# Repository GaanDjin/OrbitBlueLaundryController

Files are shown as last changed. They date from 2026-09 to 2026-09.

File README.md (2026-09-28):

# Orbit Blue Laundry Controller

## First: This project involves Fire, Moving Parts, and Mains Electricity. This can result in burning the place down, being maimed, or death so don't attempt unless you know what you are doing!

### What this is:
An ESP32 firmware designed to talk to a server laundry card tap system (Currently closed source).
RFID tap → REST deduct balance and start machine.
Three profiles divided into 2 projects at the moment: kiosk for checking, loading, and refunding card balances and then the washer/dryer which deduct card balances and control machines.
OTA updates
And remote config via heartbeat.

I took over a small laundromat in the middle of nowhere Nov. 2024 and at the time only about 50% of the machines worked which meant lots of repairing. After I had them *mostly* up and running it became obvious the coin acceptors were a bit of a nightmare. Watching people struggle to work out how the coins worked and the number of times I had to tell them which slot to put the Loonies into (makes me want to cry), I decided I needed to fix that. After looking at some of the available commercial products, which would have been nice, but way too expensive; I decided to build my own, from the ground up. 

Enter: Orbit Blue a Laundry card management system. This would be the hardware end of the system.

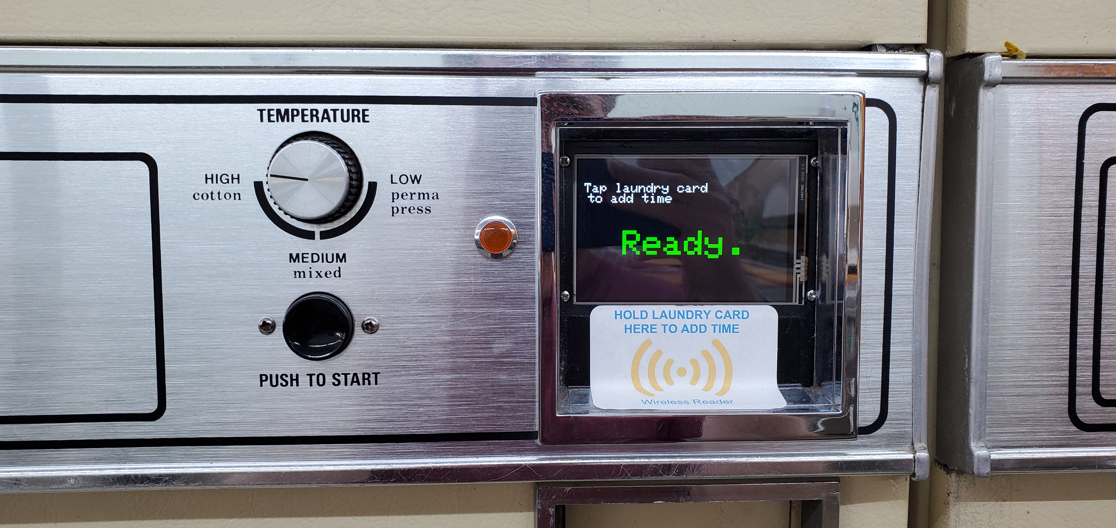
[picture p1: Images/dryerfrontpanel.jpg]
 

Video: [Dryer Start](Images/20260927_091349%20[x264].mp4)

It's hard to see in the video but as I hold the card up to the reader it starts by adding 5 minutes and then adds another 5 minutes. As timer mode is cumulative so every tap (or the longer you hold) will continue to add time up to your card balance.

Video: [Dryer Countdown](Images/20260927_091349%20[x264].mp4)

Video: [Kiosk](Images/balancechecker.mp4)

The balance checker kiosk is what I use to load and refund customer cards and guest cards (Blue fob in the video).

The project is broken into a few parts:

1. The project files for the esp32 micro controllers written in C++ using Visual Studio Code.
2. 3D files for the dryer boxes. Made to fit a Huebsch 30EG Dryer circa 1960s. Made in Blender.
3. PCB board to interface the different parts. Made in EasyEDA.

The old dryer coin drop which would accept quarters and rotate a gear and ratchet to push two switches and activate the dryer:
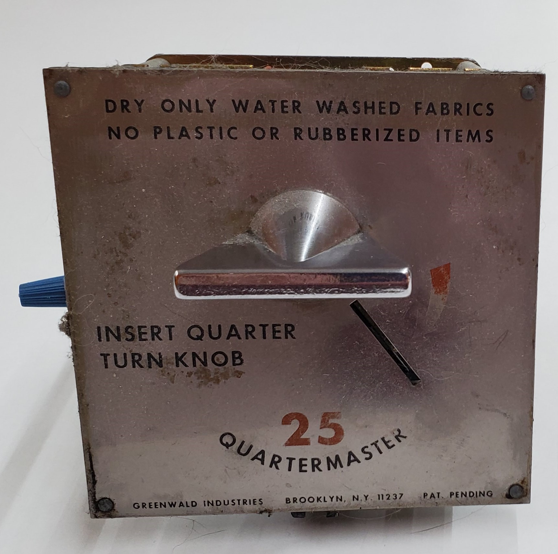
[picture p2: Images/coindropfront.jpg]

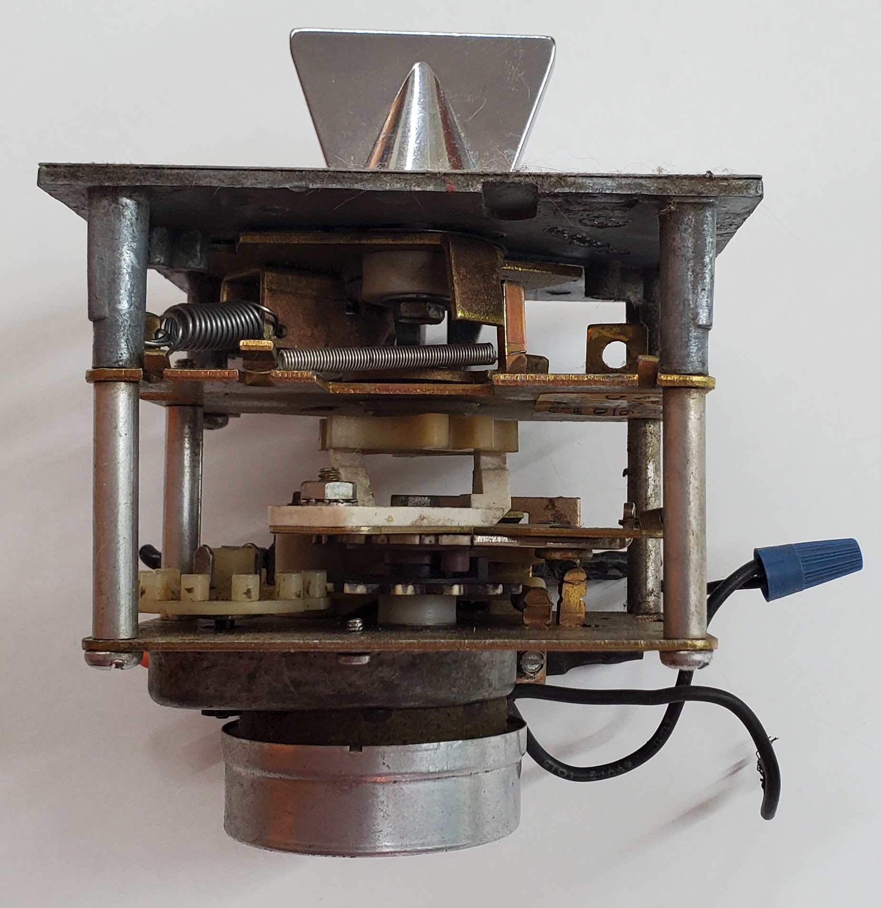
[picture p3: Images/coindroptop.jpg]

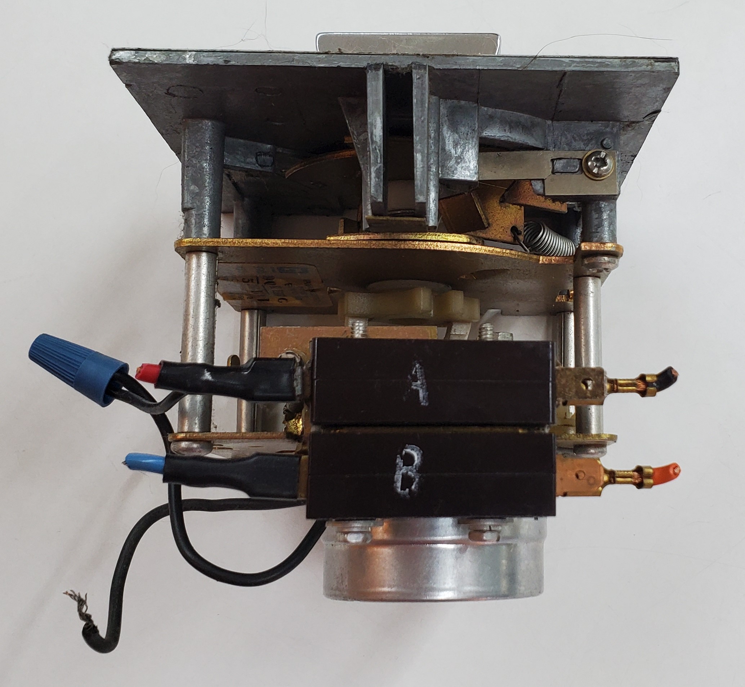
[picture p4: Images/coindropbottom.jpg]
<br />
So they've been $0.25 per 5 min for 60 years. (Or the really cheap, that figured out a Nickel would usually work too)

I tried to make the system as modular as possible so that any one module can fail and be easily replaced without tossing the whole works. I did manage to blow up a relay module putting the front panel back on and it shorted to ground. *Ka-POW* and a puff of smoke. So, again, *LINE VOLTAGE... SCARY*

A Partially assembled dryer box:<br />
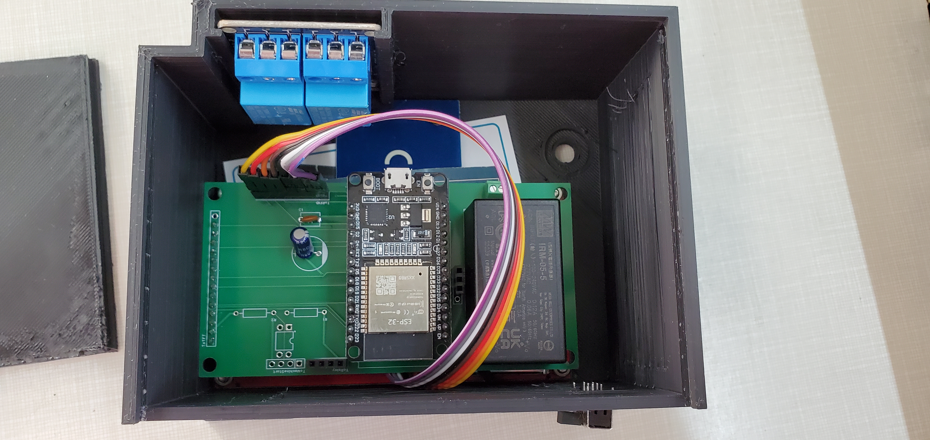
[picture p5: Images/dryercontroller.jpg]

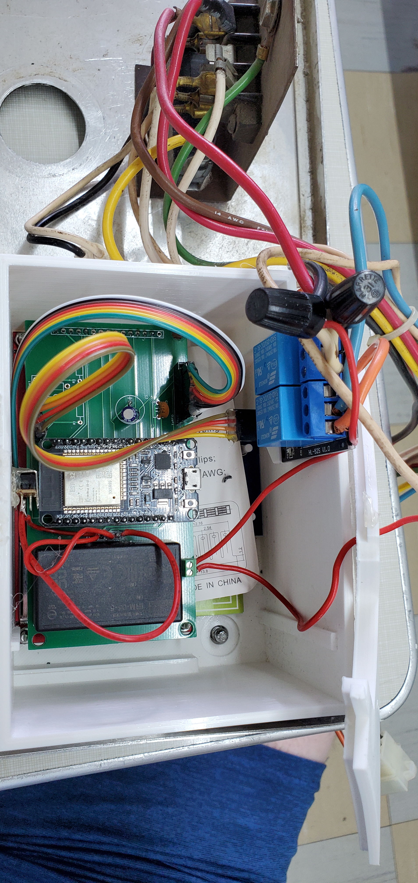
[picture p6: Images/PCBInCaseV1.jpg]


I have yet to make a box for the washer:<br />
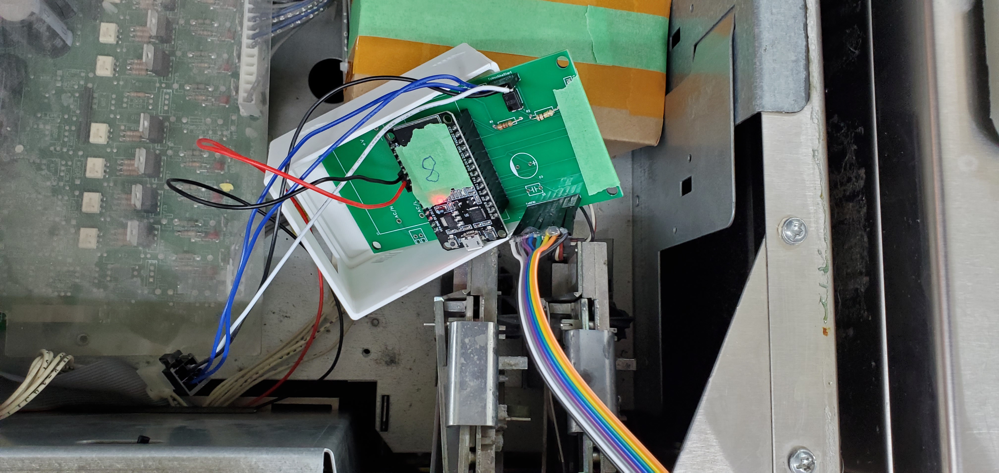
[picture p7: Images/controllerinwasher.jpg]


What the initial test looked like:<br />
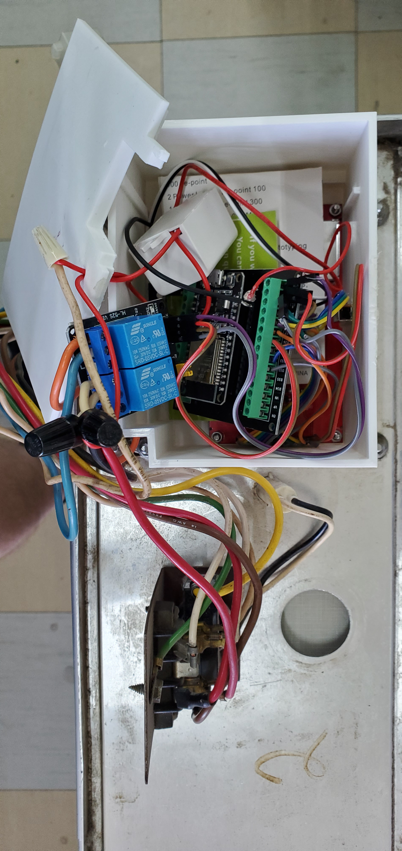
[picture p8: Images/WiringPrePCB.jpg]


The PCB just have to snip the resistor leads:<br />
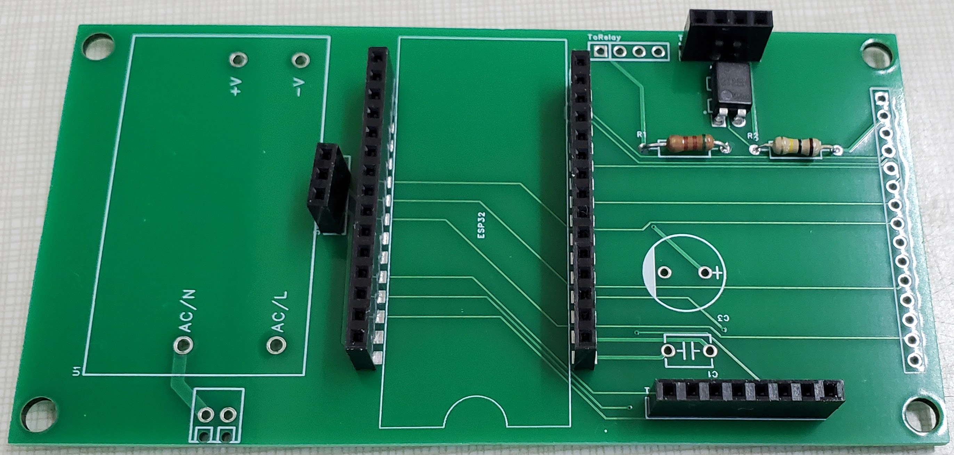
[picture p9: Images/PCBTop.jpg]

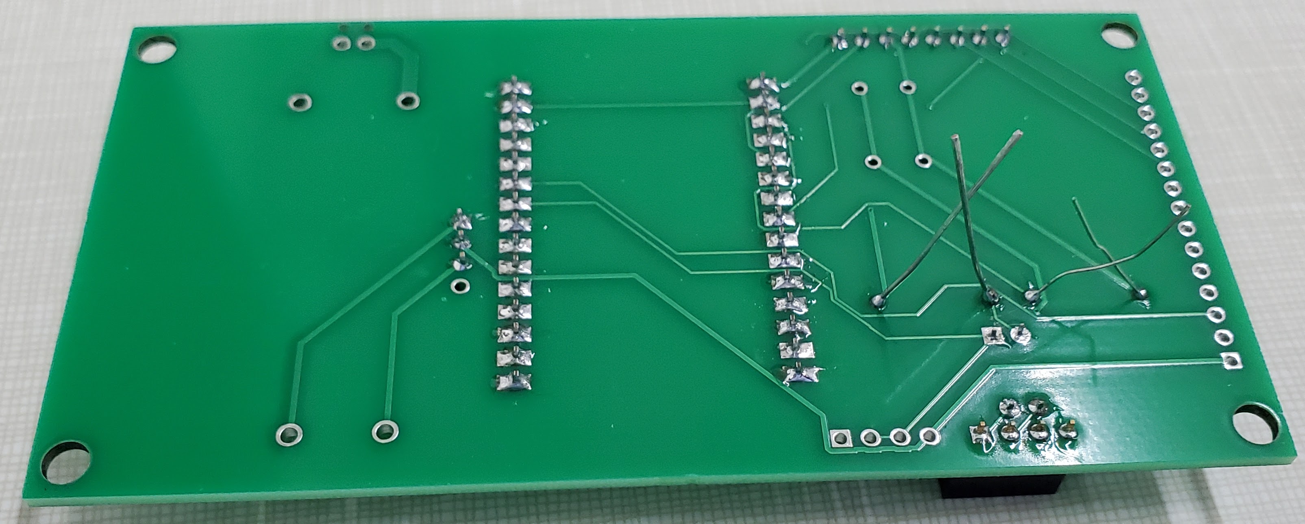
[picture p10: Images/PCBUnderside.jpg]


I designed the PCB to directly piggyback the lcd screen to save space and avoid the extra wiring.<br />
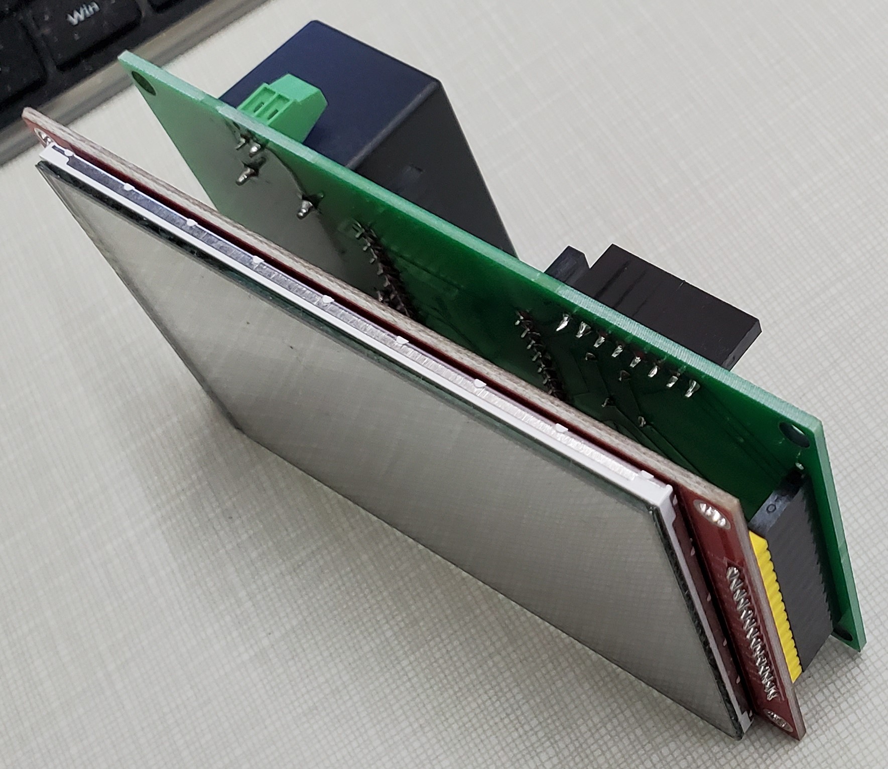
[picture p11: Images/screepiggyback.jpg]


BOM:

ASA Filament for the Dryer boxes. PLA won't cut it as the dryer heat will warp it. <br />
1 x ESP32 Dev board. Specifically: 30PIN ESP32S ESP-WROOM-32 I use [this one](https://www.amazon.ca/dp/B0BQJ8BTVB?th=1)<br />
1 x 5mm LED <-- For Washer as a status indicator<br />
1 x 100k resistor <-- Washer<br />
1 x 480 Ohm resistor <-- Washer<br />
1 x 100 nF Capacitor (#104) <-- Optional to smooth out RFID Power<br />
1 x 10 uF Capacitor <-- Optional to smooth out RFID Power<br />
1 x [6mm High Side Knob 6 Pin 2 Position DPDT Slide Switch](https://www.amazon.ca/20Pcs-50VAC-Position-Switch-SK22H03/dp/B0BKG6Y4KM) <-- Not the ones I went with as I had a bunch laying around but something similar for on/off.<br />
1 x [IRM-05-5 AC to 5v DC](https://www.digikey.ca/en/products/detail/mean-well-usa-inc/IRM-05-5/7704652) <-- A cheap buck converter isn't the greatest because of the EMI the dryers create. Needed if you can't find a 5v supply.<br />
1 x [AQY212EH Solid State Photo-Coupled Relay (Photorelay)](https://www.digikey.ca/en/products/detail/panasonic-industry/AQY212EH/512405) <-- Photo Relay for Washer<br />
1 x [Two Channel Relay Module](https://www.aliexpress.com/item/10000000669335.html?spm=a2g0o.order_list.order_list_main.147.36d618020lMnqG) <-- OR Two Channel Relay for Dryer<br />
1 x [RC522 RFID Module](https://www.digikey.ca/en/products/detail/sunfounder/CN0090/18668629) <-- *Be very wary of cheap knockoffs on Amazon and AliExpress I ended up scrapping 25 of them* Even the official ones I have to reset them every minute because they have a tendency to stop working. <br />
2 x [15-pin connection header](https://www.digikey.ca/en/products/detail/sullins-connector-solutions/PPTC151LFBN-RC/810153) <-- To mount the esp32 to the PCB<br />
1 x [14-pin connection header](https://www.digikey.ca/en/products/detail/sullins-connector-solutions/PPTC141LFBN-RC/810152) <-- To connect the LCD to the PCB<br />
1 x [8-pin connection header](https://www.digikey.ca/en/products/detail/sullins-connector-solutions/PPTC081LFBN-RC/810147) <-- To Connect the RFID to the PCB<br />
3 x [4-pin connection header](https://www.digikey.ca/en/products/detail/sullins-connector-solutions/PPTC041LFBN-RC/810144)<br />
1 x [2-pin block terminal 2.54MM PCB](https://www.digikey.ca/en/products/detail/phoenix-contact/1725656/267462)<br />
1 x [4PIN Male for PC Computer ATX CPU Power Connector](https://www.aliexpress.com/item/32607655535.html?spm=a2g0o.order_list.order_list_main.50.36d618020lMnqG)<br />
1 x [4 inch LCD Display](https://www.aliexpress.com/item/1005005787550807.html?spm=a2g0o.order_list.order_list_main.65.36d618020lMnqG)<br />
Dupont Wire Male to Female:<br />
8-pins for RFID<br />
4-pins for Relay<br />
I couldn't find a source of just male to female so went with [ELEGOO 120pcs 20cm Multicolored Dupont Wire](https://www.amazon.ca/dp/B01EV70C78?th=1) or [RGBZONE 120pcs 20CM Multicolored Dupont](https://www.amazon.ca/dp/B01M1IEUAF?th=1)<br />
Also used them as wires for the switches<br />

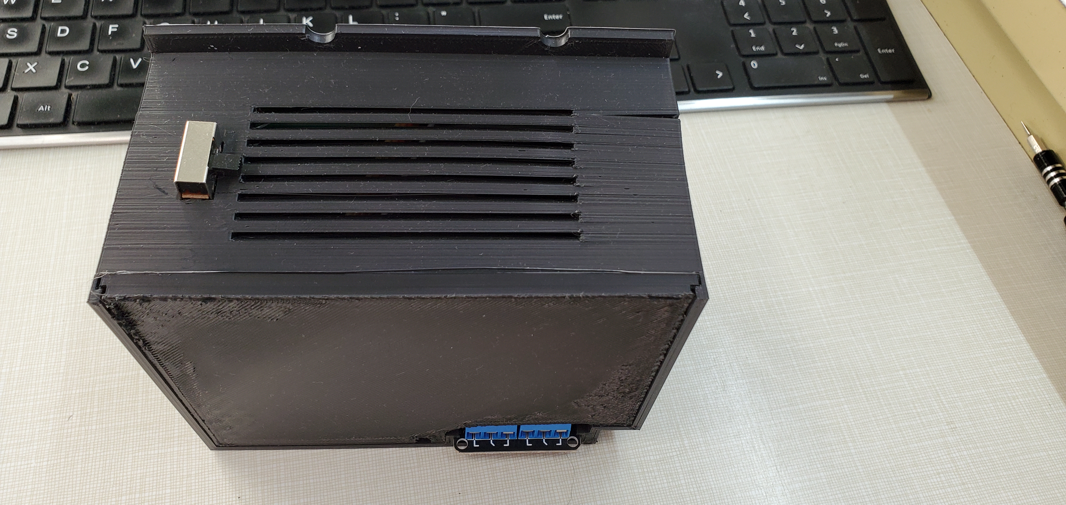
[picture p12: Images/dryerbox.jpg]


# Setup and Provisioning:
I'm going to assume a couple things so I'll glaze over installing the right drivers ([cp2102](https://www.silabs.com/software-and-tools/usb-to-uart-bridge-vcp-drivers?tab=downloads)) to talk to the esp32 and setting up PlatformIO on VS Code.

Upon initial flash the esp32 will go into provisioning mode. 
Here you can enter the wifi SSID and Password along with the login information for the controller to talk to the server. 
Once you press the "Connect & Save" button the esp32 will reboot and attempt to connect. If successful the config will be saved and you are good to go! If the login to wifi or the server fail it will reboot back to provisioning mode.

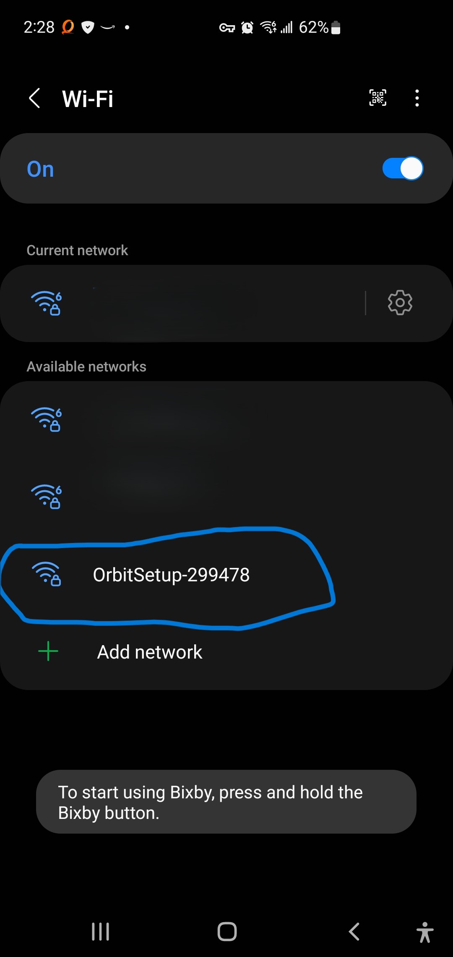
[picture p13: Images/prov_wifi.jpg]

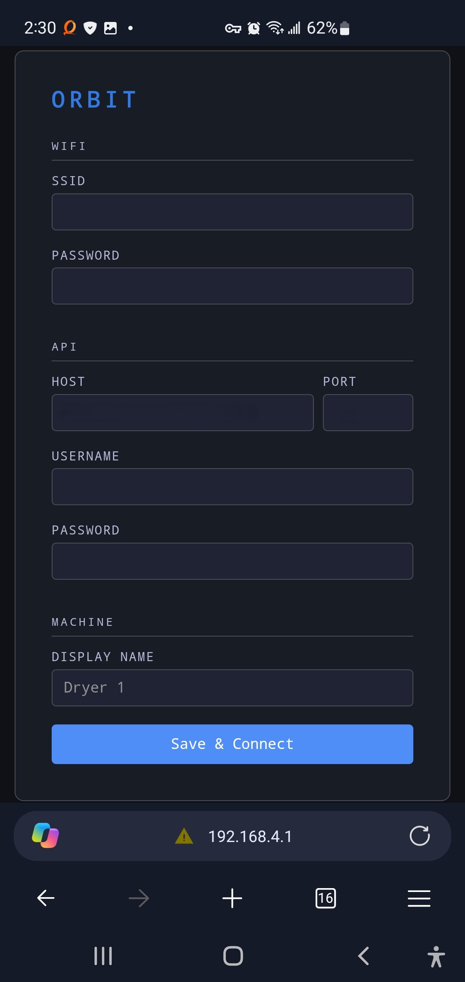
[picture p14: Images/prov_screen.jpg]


A few notes here:
The wifi must be 2.4GHz. 
The password shouldn't have any special characters in it. You might have better luck with that but I had to go Alphanumeric between all the microprocessors I have in the laundromat.
The server port is actually default port 80 unencrypted. Then switches to the specified port with SSL if port 80 failed. I found the wakeup to init into SSL was too long and people would get frustrated waiting for at least 2 seconds for the connection to be made. 

# Config in profiles:
In the platformio.ini file we can use build_flags to control some fundamental parts in the firmware:

```
    -D HAS_DISPLAY <-- When included the display will be used and when excluded the whole display library is skipped. The washer doesn't have a screen in my laundromat so this is off in the washer profile.
    -D HAS_TOUCH <-- Optional but follows the same logic as HAS_DISPLAY. When touch is enabled on the dryers it dims the screen and brightens when in use or touched.
    -D HAS_LED_RED <-- For the washers the rfid box has a red LED that will turn red upon tap and blink if there is insufficient funds. 
    -D RELAY_ON_START <-- While booting should the relay be on (Off by default). I use this on the dryer so that when the controller reboots it keeps the dryer running until it's back up and connected again.
    -D RELAY_ACTIVE=false <-- Used to indicate if the relay is closed when idle or open. Typically one would want open (Off) when idle.
    -D HAS_MACHINE_BUSY <-- Tells the esp32 to listen to the machine to determine if its running or not. While the machine is running extra taps should be ignored.
    -D FIRMWARE_PROFILE='"dev"' <-- The profile is used during OTA updating.
    -D FIRMWARE_VERSION='"1.1.2"' <-- The firmware version. Update this when making changes.
```

Config.h has some settings that can be adjusted:

```
API_HOST <-- Can be ignored. Set during provisoning.
API_PORT <-- Can be ignored. More in the provisioning section.
testInitDnsHost <-- The host to attempt to ping on boot as a network test. Doesn't affect functionality and is only useful when connected to serial or to monitor on the firewall.
CLEAR_PROVISION <-- Tells the esp32 to clear settings on boot. Needed when you want to reset the firmware to default. For instance changing the wifi password or login info on the esp32.
CLEAR_CLIENT_PREFS <-- Clears the login token on boot so the esp32 will always call /login rather than reusing the bearer token in memory.
HEARTBEAT_INTERVAL_MS <-- How often to send a heartbeat to the server. Default: 30000UL
HEARTBEAT_TIMEOUT_MS <-- How long a heartbeat should be missed before rebooting to attempt a reconnection. Default: 600000UL
TAP_COOLDOWN_MS <-- How long a card has to be visible to the reader before a new tap is registered. Used in cumulative mode. Default: 1000UL
WAKEUP_COOLDOWN_MS <-- How long between resetting the RFID reader. Default: 10000UL
ACCUM_COMMIT_OFFSET_MS <-- A buffer to wait when the card disappears before committing to deduct funds. Default: 200UL
BALANCE_DISPLAY_MS <-- How long to show the new balance on screen after funds have been deducted. Default: 10000UL
```
<br />
Globals.h

```
CONFIG_FETCH_INTERVAL_MS <-- Determines how often to get config from the server.
```

<br />
Globals.cpp stores the global variables used in the program. One variable to take not of in here is the "Amount". The default value of Amount should be set to the default price of the machines.<br /> 
I've recently had an issue with my VM Host playing up and temporarily locking up the server VM causing the controllers to reboot very infrequently. When they do reboot if they don't get a config right away this will be the amount they deduct during tap until the next time they get a config.<br />

```
double        Amount              = 5;
```

One thing to be aware of: The GFX Library for Arduino in PlatformIO is missing "esp32-hal-periman.h"<br />
```
.pio\libdeps\dev\GFX Library for Arduino\src\databus\Arduino_ESP32SPI.h
.pio\libdeps\washer\GFX Library for Arduino\src\databus\Arduino_ESP32SPI.h
.pio\libdeps\dryer\GFX Library for Arduino\src\databus\Arduino_ESP32SPI.h
```

Lines 21 & 22 need to be commented out if it complains:

```
//#include "esp32-hal-periman.h"
//#include "esp_private/periph_ctrl.h"
```

# Endpoints used:

Currently the API server I am using Orbit Blue server is closed source, But these are the endpoints the firmware uses and what they expect. Written in C#/.NET.

## POST "/Login"
Logs into the server with the username and password of the machine and then stores the bearer token data to refresh its login. 

Body: 
```
String body = "{\"username\":\"" + username + "\",\"password\":\"" + password + "\"}";
```
Response:
```
{
"accessToken": string,
"refreshToken": string,
"accessExpiresUtc": Iso8601,
"refreshExpiresUtc": Iso8601
}
```
---
## POST "/refresh"
Renew the login bearer token.

Body:
```
String body = "\" + _refreshToken + "\"";
```
Response:
```
{
"accessToken": string,
"refreshToken": string,
"accessExpiresUtc": Iso8601,
"refreshExpiresUtc": Iso8601
}
```

Iso8601 Format: YYYY-MM-DDTHH:MM:SS
Example: 2026-02-28T20:43:46.8152824+00:00

---
## GET "/accounts/current"
Used to validate the bearer token. On error attempt to log in again.
The response content is ignored here. Only that we get a 200 OK response or not. 

---
## GET "/machineconfig/current"
Gets the config from the server. Same as the UpdateConfig command from heatbeat.

Response:
```
{
  "timerMode" : bool,    <-- True: The controller should hold the relay open for cycleLengthSeconds. This is cumulative. False: the controller will pulse out to the machine start pin.
  "cycleLengthSeconds : ulong, <-- How long each tap should run for when in timer mode.
  "amount" : double, <-- How much each tap costs.
  "coinMode" : bool, <-- Coin mode determines if the controller should pulse out once for machine start or pulse repeatedly to simulate a coin drop signal. 
  "coinCount" : int, <-- The number of coin pulses to send in coin mode.
  "coinPulseDuration" : int, <-- How long the machine start and coin pulses should stay "on"
  "coinPulseDelay" : int, <-- How long to wait between coin drop pulses 
  useMachineBusy" : bool, <-- If the machine has a machine busy pin use it to update status with running and ignore taps until the machine is finished.
  "busyCooldownSeconds" : int, <-- If the machine does not have a busy pin then this is how long the controller will issue a status of busy and ignore further taps. Gives a good estimate of when a washer is busy but has no status pin.
  "screenTimeout" : int, <-- How long the screen should stay bright before dimming. 
  "timeRemaining" : int <-- When in timer mode if the esp32 controller has rebooted this can be used to tell the controller how long it has left on the current cycle.
}
```

---
## POST /machines/heartbeat
Send a status update to the server and gets a command from the server if there is one. 

Body:
```
switch (status) {
  case MachineStatus::Running:    statusStr = "Running";    break;
  case MachineStatus::Error:      statusStr = "Error";      break;
  case MachineStatus::OutOfOrder: statusStr = "OutOfOrder"; break;
  default:                        statusStr = "Idle";       break;
}

String body = {"status": status}
```
Response:
```
{
  "command": command string,
  "commandPayload", ""
}

Command String can be one of:

  "" <-- Empty no orders.
  "TryAgain"
  "AddTime" <-- commandPayload will be an int counting the number of seconds to add.
  "Cancel"
  "Reboot"
  "OutOfOrder"
  "InOrder"
  "UpdateFirmware" <-- commandPayload will be either empty or the profile to download "kiosk", "washer", or "dryer". If empty then the firmware uses whatever FIRMWARE_PROFILE was set to during initial flash.
  "UpdateConfig" <-- commandPayload will be a json object containing the controllers config:

{
  "timerMode" : bool,    <-- True: The controller should hold the relay open for cycleLengthSeconds. This is cumulative. False: the controller will pulse out to the machine start pin.
  "cycleLengthSeconds : ulong, <-- How long each tap should run for when in timer mode.
  "amount" : double, <-- How much each tap costs.
  "coinMode" : bool, <-- Coin mode determines if the controller should pulse out once for machine start or pulse repeatedly to simulate a coin drop signal. 
  "coinCount" : int, <-- The number of coin pulses to send in coin mode.
  "coinPulseDuration" : int, <-- How long the machine start and coin pulses should stay "on"
  "coinPulseDelay" : int, <-- How long to wait between coin drop pulses 
  useMachineBusy" : bool, <-- If the machine has a machine busy pin use it to update status with running and ignore taps until the machine is finished.
  "busyCooldownSeconds" : int, <-- If the machine does not have a busy pin then this is how long the controller will issue a status of busy and ignore further taps. Gives a good estimate of when a washer is busy but has no status pin.
  "screenTimeout" : int, <-- How long the screen should stay bright before dimming. 
  "timeRemaining" : int <-- When in timer mode if the esp32 controller has rebooted this can be used to tell the controller how long it has left on the current cycle.
}

```

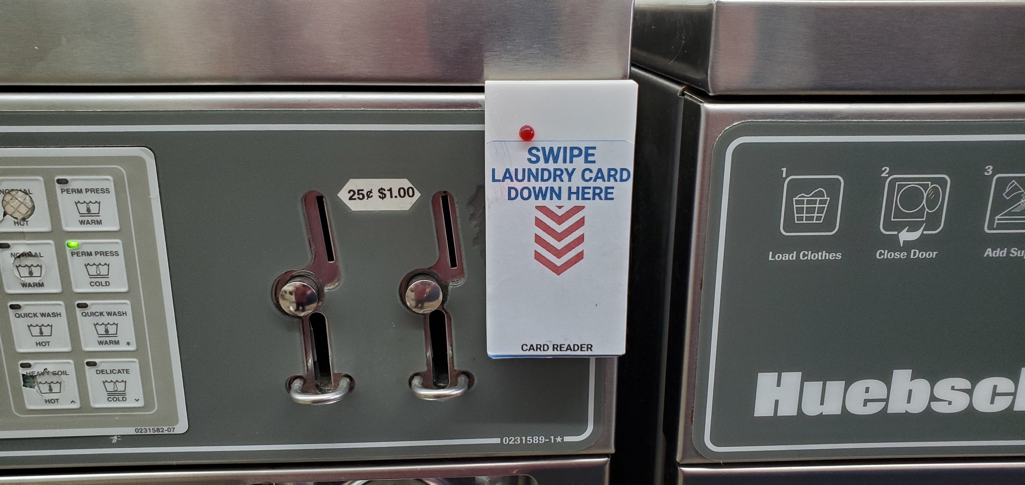
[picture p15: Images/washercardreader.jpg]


---
## POST /tap/deduct
Deduct / remove funds from a customer account given the card id.

Body:
```
String body = {"cardId": "string",  <-- The Hex ID of the RFID card. Must match a card in the database.
    "accountId": "string", <-- Originally used to identify the machine sending the deduct. Now unused always Guid.Zero
    "amount": number, <-- The amount to deduct from that customer account.
    "processorName": "CASH" <-- Processor is kind of a hint to say how this transaction was performed. Currently the firmware is set to "Cash"
    };
```
Response:
```
{
"message": string, <-- A string message if there was a problem.
"newBalance": 0.00, <-- The new account balance
"accountDisplayName": string <-- the Display name of the customer account. Currently unused by the Firmware. 
}
```

---
## POST /tap/refund
Removes funds to the customer account given the card id. Can be marked as refunded on the server to differentiate from a machine using their funds.

Body:
```
{
    "cardId": string,  <-- The Hex ID of the RFID card. Must match a card in the database.
    "amount": number, <-- The amount to refund from that customer account.
    "processorName":"CASH" <-- Processor is kind of a hint to say how this transaction was performed. Currently the firmware is set to "Cash"
}
```
Response:
```
{
"message": string, <-- A string message if there was a problem.
"newBalance": 0.00, <-- The new account balance
"accountDisplayName": string <-- the Display name of the customer account. Currently unused by the Firmware. 
}
```

---
## POST /tap/add
Add funds to the customer account given the card id.

Body:
```
{
    "cardId": string,  <-- The Hex ID of the RFID card. Must match a card in the database.
    "amount": number, <-- The amount to add to that customer account.
    "processorName": "CASH" <-- Processor is kind of a hint to say how this transaction was performed. Currently the firmware is set to "Cash"
}
```
Response:
```
{
"message": string, <-- A string message if there was a problem.
"newBalance": 0.00, <-- The new account balance
"accountDisplayName": string <-- the Display name of the customer account. Currently unused by the Firmware. 
}
```

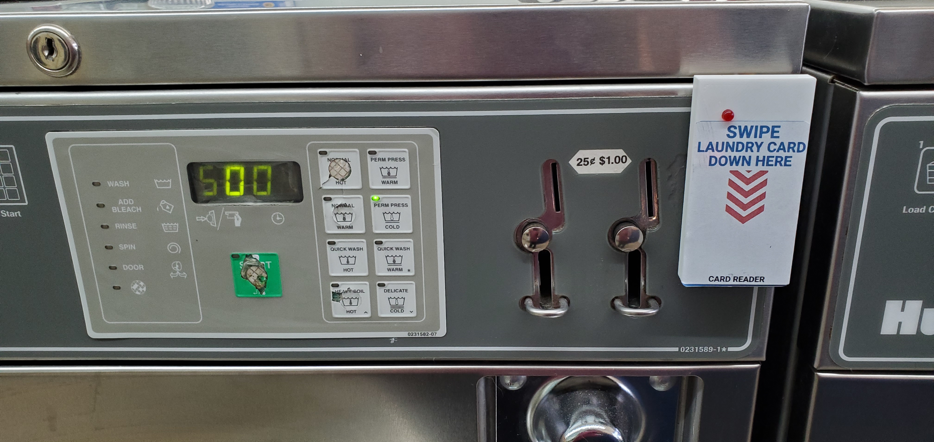
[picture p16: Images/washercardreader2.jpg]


---
## GET "/cards/list?Filters[CardId]=%cardId%"
Used to check if the card being tapped is an admin card. The response can have lots of other details but this is the only field we care about.

Response:
```
{
  rows: [
    {
      isAdminCard: bool
    } 
  ]
}
```

---
## GET "/time"
Currently unused.

---
## GET "/tap/%cardId%/balance"
```
Where %cardId% is the Hex ID of the RFID card
```
Response:
```
{
  "balance": 0.00 <-- The current balance of the customer account for that card.
}
```

---
## GET "/firmware/version?profile=" + profile
Checks to see if the server has a new firmware for an over the air update. 

Response:
```
{
  version: string <-- The version number for example "1.0.17" of the latest version on the server. If the value is different (not necessarily higher) then download the version from the server.
}
```

---
## GET "/firmware/download?profile=" + profile
Download the new firmware from the server and perform an update. As HTTPUpdate on ESP32 Arduino core doesn't support authentication this must be \[AllowAnonymous\].

Response:
```
File: application/octet-stream
```

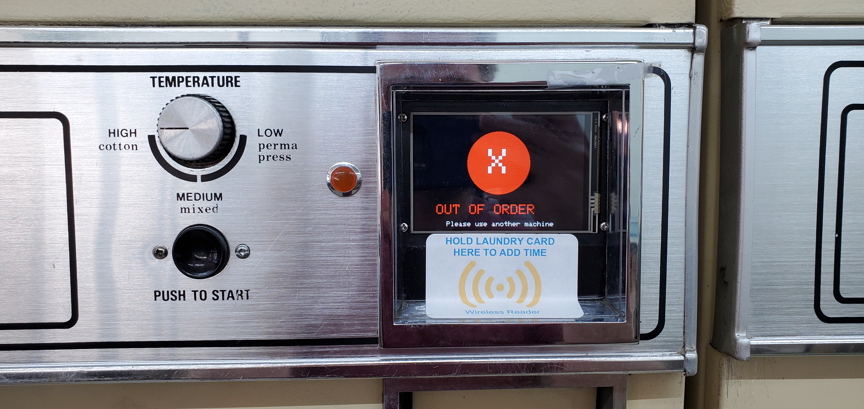
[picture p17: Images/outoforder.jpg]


There was a bit of trial and error getting the right components, learning about counterfeit electronics, and iterating through what works and what works better.
But, it has been a great project and tons of fun to go through the whole process learning how the machines work and how to interface with them. 

Hopefully, you might find this as a useful starting point for your own hardware projects. Happy building!

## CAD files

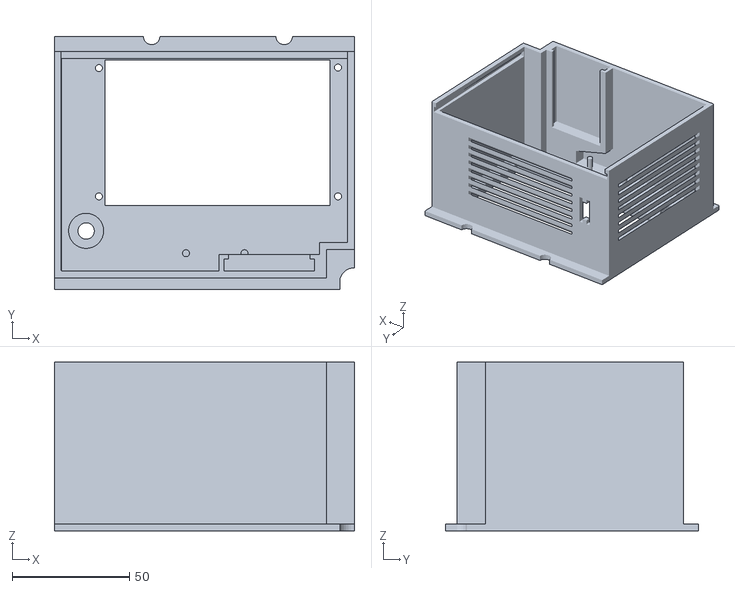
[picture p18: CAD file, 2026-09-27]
Dryer Controls - The Box v2.stl
128.0 x 108.0 x 72.0

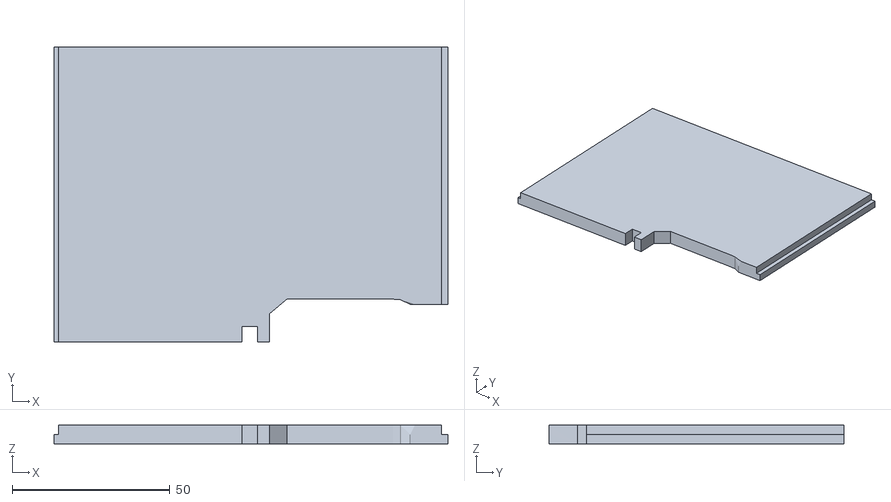
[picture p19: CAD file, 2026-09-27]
Dryer Controls - The Lid v2.stl
125.0 x 93.7 x 6.00

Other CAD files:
Dryer Timer esp32 with LCD and RFID Box.blend

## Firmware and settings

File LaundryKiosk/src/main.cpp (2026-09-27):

#include <main.h>
#include "esp_system.h"

// ── RFID objects ──────────────────────────────────────────────────────────────

#if defined(HAS_TOUCH)
  // touchSPI is owned by Touch.cpp — RFID piggybacks on the same bus
  extern SPIClass* touchSPI;
#else
  // No touch — we own the HSPI bus here
  SPIClass* touchSPI = new SPIClass(HSPI);
#endif

MFRC522DriverPinSimple* ss_pin  = nullptr;
MFRC522DriverSPI*       driver  = nullptr;
MFRC522*                mfrc522 = nullptr;


// ── Provisioned credentials ───────────────────────────────────────────────────
ProvisionData provData;

// ── Accumulation state (unused in kiosk mode, but declared in main.h) ─────────
String        accumulatingCardId  = "";
float         accumulatedAmount   = 0.0f;
int           accumulatedSeconds  = 0;
float         accumulatedBalance  = 0.0f;
unsigned long lastAccumRead       = 0;
bool          isAccumulating      = false;

// ── State ─────────────────────────────────────────────────────────────────────
static unsigned long lastHeartbeatMs = 0;

// ─────────────────────────────────────────────────────────────────────────────
// RFID helpers
// ─────────────────────────────────────────────────────────────────────────────

void setupRFID() {
#if !defined(HAS_TOUCH)
    touchSPI->begin(SPI2_SCK, SPI2_MISO, SPI2_MOSI);
#endif
    // Now construct in the correct order, after SPI bus is up
    ss_pin  = new MFRC522DriverPinSimple(RFID_SS);
    driver  = new MFRC522DriverSPI{*ss_pin, *touchSPI};
    mfrc522 = new MFRC522{*driver};

    Serial.println("[RFID] Initialising...");
    if (!mfrc522->PCD_Init()) {
        Serial.println("[RFID] Init failed!");
    } else {
        MFRC522Debug::PCD_DumpVersionToSerial(*mfrc522, Serial);
        Serial.println("[RFID] Ready.");
    }
}

String printUid(const MFRC522::Uid uid) {
        String hex = "";
    for (size_t i = 0; i < uid.size; i++) {
        if (uid.uidByte[i] < 0x10) hex += "0";
        hex += String(uid.uidByte[i], HEX);
    }
    hex.toUpperCase();
    return hex;
}

bool rfidHealthy() {
    bool ok = mfrc522 && mfrc522->PCD_PerformSelfTest();
    digitalWrite(RFID_SS, HIGH);
    touchSPI->endTransaction();
    return ok;
}

void resetRFIDModule() {
    if (mfrc522) mfrc522->PCD_Reset();
    delay(50);
    if (mfrc522) mfrc522->PCD_Init();
}

// Polls for a new card and reads its serial.
// Explicitly cleans up the SPI bus after every call so the shared HSPI bus
// is fully released before the XPT2046 touch controller gets its turn.
// Returns true if a card UID is ready in mfrc522->uid.
static bool rfidPoll() {
    bool cardPresent = mfrc522->PICC_IsNewCardPresent();
    // RFID_SS may still be asserted — force deassert and close any open transaction
    digitalWrite(RFID_SS, HIGH);
    touchSPI->endTransaction();

    if (!cardPresent) return false;

    bool gotSerial = mfrc522->PICC_ReadCardSerial();
    digitalWrite(RFID_SS, HIGH);
    touchSPI->endTransaction();

    return gotSerial;
}

// ─────────────────────────────────────────────────────────────────────────────
// Machine stubs (kiosk — no relay, no cycle)
// ─────────────────────────────────────────────────────────────────────────────

void  startMachineCycle()             { /* kiosk: not used */ }
void  addCycleTime(int /*seconds*/)   { /* kiosk: not used */ }
void  cancelCycle()                   { /* kiosk: not used */ }
bool  machineIsRunning()              { return false; }
void  commitAccumulation()            { /* kiosk: not used */ }
void  applyConfig(const String& /*j*/){ /* kiosk: not used */ }
void  fetchConfig()                   { /* kiosk: not used */ }

// ─────────────────────────────────────────────────────────────────────────────
// WiFi
// ─────────────────────────────────────────────────────────────────────────────

void connectWifi() {
    showConnecting();
    WiFi.mode(WIFI_STA);
    WiFi.begin(provData.wifiSsid.c_str(), provData.wifiPass.c_str());
    unsigned long start = millis();
    while (WiFi.status() != WL_CONNECTED) {
        if (millis() - start > 15000) {
            Serial.println("[WiFi] Timeout — rebooting.");
            ESP.restart();
        }
        delay(250);
    }
    showConnected();
    Serial.println("[WiFi] Connected: " + WiFi.localIP().toString());
}

// ─────────────────────────────────────────────────────────────────────────────
// Auth
// ─────────────────────────────────────────────────────────────────────────────


bool ensureAuthenticated() {
    // Wait for NTP to sync so time() is valid for expiry checks
    time_t now = time(nullptr);
    while (now < 1000000000UL) {
        delay(100);
        now = time(nullptr);
    }

    // Try to load cached credentials
    if (api->loadCredentials()) {
        if (api->needsRelogin()) {
            Serial.println("[Auth] Refresh token expired — full login.");
        } else if (api->needsRefresh()) {
            Serial.println("[Auth] Access token expiring — refreshing.");
            if (api->refreshToken()) return true;
            Serial.println("[Auth] Refresh failed — full login.");
        } else {
            // Verify the cached token actually works before trusting it
            // This catches wrong port/host after re-provisioning
            Serial.println("[Auth] Verifying cached token...");
            String response;
            if (api->get("/accounts/current", response, true)) {
                Serial.println("[Auth] Cached token valid.");
                return true;
            }
            Serial.println("[Auth] Cached token rejected — full login.");
            api->clearCredentials();
        }
    }

    // Full login
    Serial.println("[Auth] Logging in...");
    if (api->login(provData.apiUser, provData.apiPass)) {
        Serial.println("[Auth] Logged in!");
        if (!provData.verified) {
            markProvisionVerified();
            provData.verified = true;
        }
        return true;
    }

    Serial.println("[Auth] Login failed!");
    if (!provData.verified) {
        // Never successfully logged in — bad credentials, reprovision
        Serial.println("[Auth] Never verified — clearing provisioning.");
        clearProvisionData();
    } else {
        // Worked before — infrastructure problem, reboot and retry
        Serial.println("[Auth] Previously verified — rebooting to retry.");
    }
    #if defined(HAS_DISPLAY)
        showRebooting();
    #endif
    delay(1000);
    ESP.restart();
    return false;  // unreachable
}

// ─────────────────────────────────────────────────────────────────────────────
// Heartbeat  (always reports Idle for the kiosk)
// ─────────────────────────────────────────────────────────────────────────────

void doHeartbeat() {
    if (millis() - lastHeartbeat < HEARTBEAT_INTERVAL_MS) return;
    lastHeartbeat = millis();

    MachineStatus currentStatus = isOutOfOrder        ? MachineStatus::OutOfOrder
                                 : machineIsRunning() ? MachineStatus::Running
                                                      : MachineStatus::Idle;
    HeartbeatResponse hb = api->sendHeartbeat(currentStatus);

    if (!hb.ok) {
        Serial.println("[Heartbeat] Failed — will retry next cycle");


        // Heartbeat hasn't succeeded in too long (server unreachable)
        if (lastHeartbeat - lastSuccessfulHeartbeat > HEARTBEAT_TIMEOUT_MS) {
            Serial.println("[Heartbeat] Timeout — rebooting.");
            ESP.restart();
        }

        return;
    }

    lastSuccessfulHeartbeat =  millis();

    switch (hb.command) {
        case MachineCommand::None:                                         break;
        case MachineCommand::TryAgain:    startMachineCycle();            break;
        case MachineCommand::AddTime:     addCycleTime(hb.commandPayload.toInt()); break;
        case MachineCommand::Cancel:      cancelCycle();                  break;
        case MachineCommand::UpdateConfig: applyConfig(hb.commandPayload); break;
        case MachineCommand::UpdateFirmware:
            Serial.println("[OTA] Update command received.");
            #if defined(HAS_DISPLAY)
                // TODO: showUpdating();
            #endif
            api->checkAndApplyFirmwareUpdate(
                hb.commandPayload.isEmpty() ? String(FIRMWARE_PROFILE) : hb.commandPayload,
                String(FIRMWARE_VERSION));
            break;
        case MachineCommand::Reboot:
#if defined(HAS_DISPLAY)
            showRebooting();
#endif
            delay(1000);
            ESP.restart();
            break;
        case MachineCommand::OutOfOrder:
            Serial.println("[Machine] Out of order.");
            isOutOfOrder = true;
            #if defined(HAS_DISPLAY)
                showOutOfOrder();
            #endif
            break;
        case MachineCommand::InOrder:
            Serial.println("[Machine] Back in order.");
            isOutOfOrder = false;
            #if defined(HAS_DISPLAY)
                showReady();
            #endif
            break;
    }
}


// ─────────────────────────────────────────────────────────────────────────────
// Kiosk state machine
// ─────────────────────────────────────────────────────────────────────────────

enum class KioskState : uint8_t {
    IDLE,
    BALANCE_SHOWN,       // balance on screen, Admin button visible
    ADMIN_MENU,          // Add / Deduct / Back
    ADMIN_AMOUNT,        // numpad — enter dollar amount
    ADMIN_AWAITING_CARD, // waiting for admin tap to authorise
    ADMIN_RESULT,        // brief success/fail screen
};

static KioskState       kioskState       = KioskState::IDLE;
static unsigned long    stateEnteredMs   = 0;
static String           pendingCardId    = "";    // customer card receiving funds
static float            pendingAmount    = 0.0f;  // amount entered on numpad
static String           amountStr       = "";    // raw digit string while typing
static bool             pendingIsDeduct  = false; // true = deduct, false = add

static void enterState(KioskState s) {
    kioskState     = s;
    stateEnteredMs = millis();
}

// ─────────────────────────────────────────────────────────────────────────────
// Touch helpers
// XPT2046 with setRotation(3): raw X maps to screen X (0-480),
// raw Y maps to screen Y (0-320).  Calibration is approximate — adjust the
// min/max constants if your panel reads differently.
// ─────────────────────────────────────────────────────────────────────────────

#if defined(HAS_TOUCH)
static const int TS_MINX = 200,  TS_MAXX = 3800;
static const int TS_MINY = 200,  TS_MAXY = 3800;
static const int SCR_W   = 480,  SCR_H   = 320;

struct TPoint { int x; int y; bool valid; };

static TPoint getTouchPoint() {
    if (!touch->tirqTouched() || !touch->touched())
        return {0, 0, false};
    TS_Point p = touch->getPoint();
    int sx = map(p.x, TS_MINX, TS_MAXX, 0, SCR_W);
    int sy = map(p.y, TS_MINY, TS_MAXY, 0, SCR_H);
    sx = constrain(sx, 0, SCR_W - 1);
    sy = constrain(sy, 0, SCR_H - 1);
    
    Serial.printf("\n[Touch] Touchpoint: %d, %d\n", sx, sy);

    return {sx, sy, true};
}

static bool hitTest(int tx, int ty, int bx, int by, int bw, int bh) {
    return tx >= bx && tx < bx + bw && ty >= by && ty < by + bh;
}
#endif

// ─────────────────────────────────────────────────────────────────────────────
// Screen drawing helpers
// ─────────────────────────────────────────────────────────────────────────────

#if defined(HAS_DISPLAY)

// Draws a filled rounded button with centred label
static void drawButton(int x, int y, int w, int h,
                       uint16_t bg, uint16_t fg,
                       const char* label, uint8_t textSize = 2) {
                    
    Serial.printf("[Display] Draw Button: %d, %d, %d, %d\n", x, y, w, h);
    
    gfx->fillRoundRect(x, y, w, h, 6, bg);
    gfx->drawRoundRect(x, y, w, h, 6, fg);
    gfx->setTextSize(textSize);
    gfx->setTextColor(fg, bg);
    int16_t x1, y1; uint16_t tw, th;
    gfx->getTextBounds(label, 0, 0, &x1, &y1, &tw, &th);
    gfx->setCursor(x + (w - tw) / 2 - x1, y + (h - th) / 2 - y1);
    gfx->print(label);
}

// ── Admin button geometry (top-right corner) ──────────────────────────────────
#define ADMIN_BTN_X  370
#define ADMIN_BTN_Y    6
#define ADMIN_BTN_W   104
#define ADMIN_BTN_H    36

static void drawAdminButton() {
    drawButton(ADMIN_BTN_X, ADMIN_BTN_Y, ADMIN_BTN_W, ADMIN_BTN_H,
               0x2104 /*dark grey*/, WHITE, "Admin", 2);
}

#endif // HAS_DISPLAY

// ─────────────────────────────────────────────────────────────────────────────
// Idle screen
// ─────────────────────────────────────────────────────────────────────────────

static void showKioskIdle() {
    pendingCardId = "";
    pendingAmount = 0.0f;
    amountStr     = "";
    enterState(KioskState::IDLE);
#if defined(HAS_DISPLAY)
    gfx->fillScreen(BLACK);
    gfx->setTextColor(GREEN, BLACK);
    gfx->setTextSize(4);
    gfx->setCursor(80, 130);
    gfx->print("Check your");
    gfx->setCursor(60, 185);
    gfx->print("Balance here");
#endif
}

// ─────────────────────────────────────────────────────────────────────────────
// Balance screen  (with Admin button)
// ─────────────────────────────────────────────────────────────────────────────

static void showBalance(float balance, const String& cardId) {
    pendingCardId = cardId;
    enterState(KioskState::BALANCE_SHOWN);
#if defined(HAS_DISPLAY)
    gfx->fillScreen(BLACK);

    // "Balance" label
    gfx->setTextSize(4);
    gfx->setTextColor(WHITE, BLACK);
    gfx->setCursor(140, 100);
    gfx->print("Balance");

    // Dollar amount — large, centred
    char buf[16];
    snprintf(buf, sizeof(buf), "$%.2f", balance);
    gfx->setTextSize(8);
    gfx->setTextColor(GREEN, BLACK);
    int16_t x1, y1; uint16_t w, h;
    gfx->getTextBounds(buf, 0, 0, &x1, &y1, &w, &h);
    gfx->setCursor((SCR_W - w) / 2 - x1, 175);
    gfx->print(buf);

    drawAdminButton();
#endif
}

// ── Admin menu ───────────────────────────────────────────────────────────────
#define MENU_BTN_W  130
#define MENU_BTN_H   70
#define MENU_BTN_Y  110
#define MENU_ADD_X   30
#define MENU_DED_X  175
#define MENU_BCK_X  320
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
void loop() {
    unsigned long now = millis();

    // ── Heartbeat ────────────────────────────────────────────────────────────
    doHeartbeat();

    // ── WiFi watchdog ─────────────────────────────────────────────────────────
    if (WiFi.status() != WL_CONNECTED) {
        if (now - lastWifiCheck > 30000UL) {
            lastWifiCheck = now;
            Serial.println("[WiFi] Still disconnected...");
            if (now - lastWifiConnected > 120000UL) {
                Serial.println("[WiFi] Rebooting.");
                ESP.restart();
            }
        }
    } else {
        lastWifiConnected = now;
    }

    // ── Token refresh ─────────────────────────────────────────────────────────
    if      (api->needsRelogin())  api->login(provData.apiUser, provData.apiPass);
    else if (api->needsRefresh() && !api->refreshToken())  api->login(provData.apiUser, provData.apiPass);

    // ── BALANCE_SHOWN / ADMIN_RESULT timeout → back to IDLE ─────────────────
    if (kioskState == KioskState::BALANCE_SHOWN &&
        now - stateEnteredMs > BALANCE_DISPLAY_MS)
    {
        showKioskIdle();
        return;
    }
    if (kioskState == KioskState::ADMIN_RESULT &&
        now - stateEnteredMs > RESULT_DISPLAY_MS)
    {
        showKioskIdle();
        return;
    }

    // ── Touch handling ────────────────────────────────────────────────────────
#if defined(HAS_TOUCH)
    static bool lastTouched = false;
    TPoint tp = getTouchPoint();

    // Edge-detect: only fire once on press-down, ignore held touch
    if (tp.valid && !lastTouched) {
        lastTouched    = true;
        lastScreenTime = now;

        switch (kioskState) {

        case KioskState::BALANCE_SHOWN:
            // Admin button — top right
            if (hitTest(tp.x, tp.y, ADMIN_BTN_X, ADMIN_BTN_Y, ADMIN_BTN_W, ADMIN_BTN_H)) {
                Serial.println("[Admin] Admin button pressed.");
                enterState(KioskState::ADMIN_MENU);
#if defined(HAS_DISPLAY)
                drawAdminMenu();
#endif
            }
            break;

        case KioskState::ADMIN_MENU:
            if (hitTest(tp.x, tp.y, MENU_ADD_X, MENU_BTN_Y, MENU_BTN_W, MENU_BTN_H)) {
                Serial.println("[Admin] Add selected.");
                pendingIsDeduct = false;
                amountStr = "";
                enterState(KioskState::ADMIN_AMOUNT);
#if defined(HAS_DISPLAY)
                drawNumpad();
#endif
            } else if (hitTest(tp.x, tp.y, MENU_DED_X, MENU_BTN_Y, MENU_BTN_W, MENU_BTN_H)) {
                Serial.println("[Admin] Refund selected.");
                pendingIsDeduct = true;
                amountStr = "";
                enterState(KioskState::ADMIN_AMOUNT);
#if defined(HAS_DISPLAY)
                drawNumpad();
#endif
            } else if (hitTest(tp.x, tp.y, MENU_BCK_X, MENU_BTN_Y, MENU_BTN_W, MENU_BTN_H)) {
                Serial.println("[Admin] Back pressed.");
                // Re-show balance screen — re-fetch so it's fresh
                float bal;
                if (api->getBalance(pendingCardId, bal))
                    showBalance(bal, pendingCardId);
                else
                    showKioskIdle();
            }
            break;

        case KioskState::ADMIN_AMOUNT: {
            // Cancel
            if (hitTest(tp.x, tp.y, CANCEL_BTN_X, CANCEL_BTN_Y, CANCEL_BTN_W, CANCEL_BTN_H)) {
                Serial.println("[Admin] Cancelled.");
                showKioskIdle();
                break;
            }
            // Enter button
            if (hitTest(tp.x, tp.y, ENTER_BTN_X, ENTER_BTN_Y, ENTER_BTN_W, ENTER_BTN_H)) {
                if (handleNumpadKey('E')) {
                    enterState(KioskState::ADMIN_AWAITING_CARD);
#if defined(HAS_DISPLAY)
                    drawAwaitingAdminCard();
#endif
                }
                break;
            }
            // Digit rows
            char pressedKey = 0;
            for (int r = 0; r < 3 && !pressedKey; r++) {
                for (int c = 0; c < 3 && !pressedKey; c++) {
                    int bx = NP_ORIG_X + c*(NP_BTN_W+NP_GAP);
                    int by = NP_ORIG_Y + r*(NP_BTN_H+NP_GAP);
                    if (hitTest(tp.x, tp.y, bx, by, NP_BTN_W, NP_BTN_H))
                        pressedKey = NP_KEYS[r][c];
                }
            }
            // Bottom row
            if (!pressedKey) {
                int by = NP_ORIG_Y + 3*(NP_BTN_H+NP_GAP);
                for (int c = 0; c < 3 && !pressedKey; c++) {
                    int bx = NP_ORIG_X + c*(NP_BTN_W+NP_GAP);
                    if (hitTest(tp.x, tp.y, bx, by, NP_BTN_W, NP_BTN_H))
                        pressedKey = NP_BOT[c];
                }
            }
            if (pressedKey) {
                handleNumpadKey(pressedKey);
#if defined(HAS_DISPLAY)
                refreshAmountDisplay();
#endif
            }
            break;
        }

        case KioskState::ADMIN_AWAITING_CARD:
            // Cancel only — card tap is handled below in the RFID block
            if (hitTest(tp.x, tp.y, CANCEL_BTN_X, CANCEL_BTN_Y, CANCEL_BTN_W, CANCEL_BTN_H)) {
                Serial.println("[Admin] Awaiting-card cancelled.");
                showKioskIdle();
            }
            break;

        default:
            break;
        }
    }
    if (!tp.valid) lastTouched = false;
#endif // HAS_TOUCH

    // ── RFID scan ──────────────────────────────────────────────────────────────
    if (now - lastTapTime > TAP_COOLDOWN_MS && rfidPoll())
    {
        lastTapTime    = now;
        lastScreenTime = now;
        String cardID  = printUid(mfrc522->uid);
        mfrc522->PICC_HaltA();
        mfrc522->PCD_StopCrypto1();
        Serial.println("[RFID] Tap: " + cardID);

        if (kioskState == KioskState::ADMIN_AWAITING_CARD) {
            // ── Admin card verification + fund transfer ──────────────────
            Serial.println("[Admin] Checking card: " + cardID);
            if (!api->isAdmin(cardID)) {
                Serial.println("[Admin] Not an admin card.");
#if defined(HAS_DISPLAY)
                drawAdminResult(false, 0.0f, "Not admin card");
#endif
            } else {
                float newBalance = 0.0f;
                bool ok;
                if (pendingIsDeduct) {
                    String result, displayName;
                    String accountId;
                    ok = api->refund(pendingCardId, accountId, pendingAmount,
                                     String("Cash"), result, newBalance, displayName);
                    Serial.printf("[Admin] refund %s  msg=%s  newBal=%.2f\n",
                                  ok ? "OK" : "FAIL", result.c_str(), newBalance);
                } else {
                    ok = api->addFunds(pendingCardId, pendingAmount, newBalance);
                    Serial.printf("[Admin] addFunds %s  newBal=%.2f\n",
                                  ok ? "OK" : "FAIL", newBalance);
                }
#if defined(HAS_DISPLAY)
                if (ok) drawAdminResult(true,  newBalance, "");
                else    drawAdminResult(false, 0.0f, "Transfer failed");
#endif
            }
        } else {
            // ── Normal tap: show balance ───────────────────────────────
            float bal;
            if (!api->getBalance(cardID, bal)) {
                Serial.println("[Tap] Balance lookup failed.");
#if defined(HAS_DISPLAY)
                gfx->fillScreen(BLACK);
                gfx->setTextSize(3);
                gfx->setTextColor(RED, BLACK);
                gfx->setCursor(80, 160);
                gfx->print("Card not found");
#endif
                enterState(KioskState::BALANCE_SHOWN); // still times out to idle
            } else {
                Serial.printf("[Tap] Balance: $%.2f\n", bal);
                showBalance(bal, cardID);
            }
        }
    }
}

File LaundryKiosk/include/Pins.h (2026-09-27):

/*
D4   — RFID RST
D5   — RFID SS
D12  — HSPI MISO  (Touch TD0 + RFID MISO shared)
D13  — HSPI MOSI  (Touch TDI + RFID MOSI shared)
D14  — HSPI SCK   (Touch TCK + RFID SCK shared)
D15  — MACHINE_BUSY (washer units)
D18  — TFT SCK    (dryer units)
D19  — reserved for later
D21  — TFT DC     (dryer units)
D22  — TFT RST    (dryer units)
D23  — TFT SDI    (dryer units)
D25  — TOUCH IRQ  (dryer units)
D26  — RELAY
D27  — TFT CS     (dryer units)
D32  — TFT BL     (dryer units)
D33  — TOUCH CS   (dryer units)
D2   — LED RED    (washer units)
*/

#pragma once

#include <Config.h>

// ── Shared SPI bus (HSPI) — Touch + RFID ─────────────────────────────────────
#define SPI2_SCK  14
#define SPI2_MISO 12
#define SPI2_MOSI 13

// ── RFID ──────────────────────────────────────────────────────────────────────
#define RFID_SS  5
#define RFID_RST 4

// ── TFT display ───────────────────────────────────────────────────────────────
#if defined(HAS_DISPLAY)
  #define TFT_CS  27
  #define TFT_DC  21
  #define TFT_RST 22
  #define TFT_BL  32   // PWM backlight — GPIO32
  #define BL_BRIGHT 255
  #define BL_DIM      32
#endif

// ── Touch ─────────────────────────────────────────────────────────────────────
#if defined(HAS_TOUCH)
  #define TOUCH_CS  33
  #define TOUCH_IRQ 25
#endif

// ── LEDs ──────────────────────────────────────────────────────────────────────
#if defined(HAS_LED_GREEN)
  #define LED_GREEN_PIN 0   // TODO: assign a free pin if LED ever used on kiosk
#endif

#if defined(HAS_LED_RED)
  #define LED_RED_PIN 2     // adjust to your wiring
#endif

// ── Machine IO ────────────────────────────────────────────────────────────────
#define RELAY1 26

#if defined(HAS_MACHINE_BUSY)
  #define MACHINE_BUSY 15
#endif

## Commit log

2026-09-27 PCB Design
2026-09-27 Initial Upload
    The 3D Model of the dryer Box and Lid.
    [Dryer Controls - The Box v2.stl, Dryer Controls - The Lid v2.stl, Dryer Timer esp32 with LCD and RFID Box.blend]
2026-09-27 Start Dryer Timer
2026-09-27 Dryer Timer End
2026-09-27 Delete PCBInCaseV1.jpg
    Moved to Images directory.
2026-09-27 Delete WiringPrePCB.jpg
    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
2026-09-27 Delete PCBUnderside.jpg
    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
2026-09-27 Delete PCBTop.jpg
    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
2026-09-28 Enhance README with setup and provisioning details
    Added setup and provisioning instructions for ESP32, including configuration details and API endpoints.
